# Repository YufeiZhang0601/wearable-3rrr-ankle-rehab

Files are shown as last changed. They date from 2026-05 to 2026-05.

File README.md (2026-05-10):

# Wearable 3-RRR Ankle Rehabilitation Robot

URDF, kinematic model, and ROS 2 control demos for a wearable three-degree-of-freedom (3-DOF) ankle rehabilitation robot built on a 3-RRR spherical parallel mechanism (SPM). The device's remote center of rotation is co-located with the human talocrural / subtalar complex, enabling clinically meaningful pitch (dorsiflexion / plantarflexion), roll (inversion / eversion), and yaw (internal / external rotation) without parasitic shear loads.

The accompanying paper, *Design, Kinematic Optimization, and Assist-As-Needed Control of a Wearable 3-RRR Spherical Parallel Ankle Rehabilitation Robot*, is built from the LaTeX sources in [`report/`](report/).

A short demonstration of the closed-loop tracking running against the URDF model is available at [`media/closed_loop_demo.mp4`](media/closed_loop_demo.mp4) (≈ 25 MB).

---

## Repository layout

```
.
├── rh1/                          ROS 2 ament_python package (Python module)
│   ├── ankle_rehab_control.py            shared trajectory + safety utilities
│   ├── ankle_rehab_joint_state_player.py ROS 2 node: publish JointState for RViz/Gazebo
│   ├── parallel_ik.py                    numerical inverse kinematics for the 3-RRR SPM
│   └── parallel_ik_pose_demo.py          ROS 2 node: command roll/pitch/yaw at runtime
├── urdf/
│   ├── rh1.urdf                          full URDF exported from SolidWorks
│   └── rh1_sim.urdf.xacro                lightweight RViz/Gazebo-friendly model
├── meshes/
│   ├── visual/    *.STL                  visual meshes referenced by urdf/rh1.urdf
│   └── collision/ *.STL                  collision meshes
├── launch/
│   ├── display_robot.launch.py           RViz visualization
│   ├── ankle_rehab_demo.launch.py        scripted ankle rehab trajectory demo
│   ├── parallel_ik_pose_demo.launch.py   interactive parallel-IK demo
│   └── gazebo.launch.py                  Gazebo bring-up
├── rviz/                          RViz configurations
├── config/                        runtime config (auto-generated parallel-IK params)
├── params/                        kinematic and parallel-IK parameter templates
│   ├── kinematic_params.template.yaml
│   ├── kinematic_params.candidate.yaml
│   ├── parallel_ik_params.template.json
│   ├── parallel_ik_params.example.json
│   └── parallel_ik_params.autogenerated.json
├── scripts/                       standalone CLI tools (no ROS dependency)
│   ├── ankle_rehab_closed_loop_demo.py     URDF-based closed-loop demo (CSV log)
│   ├── parallel_ik_demo.py                 one-shot pose → motor angles
│   ├── auto_generate_parallel_ik_params.py bootstraps parameters from CAD extraction
│   ├── extract_step_kinematics.py          mines kinematic candidates from STEP files
│   └── record_ankle_rehab_demo.ps1         screen-record helper for the demo
├── media/                         demo recordings
│   └── closed_loop_demo.mp4              short clip of the closed-loop tracking demo
├── docs/                          English documentation
│   ├── ankle_rehab_demo.md
│   ├── parallel_ik_derivation.md
│   ├── parallel_ik_ros_demo.md
│   ├── kinematics_extraction.md
│   └── legacy/course_reports/     archived AMR Project 1 / 3 LaTeX sources
├── report/                        IEEE-style report sources (LaTeX + figures)
│   ├── main.tex
│   ├── references.bib
│   └── figures/
├── test/                          ament linter tests
├── resource/rh1                   ament resource marker (do not rename)
├── package.xml
├── setup.py / setup.cfg
└── README.md
```

---

## Quick start

### 1. Pure Python closed-loop demo (no ROS required)

```powershell
python scripts\ankle_rehab_closed_loop_demo.py
```

Parses `urdf/rh1.urdf`, treats `joint1`, `joint4`, `joint6` as the three Dynamixel XM430-W350-R virtual actuators, tracks a slow, low-amplitude rehab trajectory, and writes feedback to `demo_output/ankle_rehab_closed_loop.csv`. See [`docs/ankle_rehab_demo.md`](docs/ankle_rehab_demo.md) for arguments and safety notes.

### 2. One-shot inverse kinematics

```powershell
python scripts\parallel_ik_demo.py --roll-deg 5 --pitch-deg 10 --yaw-deg 0
```

Solves the parallel IK for one foot-plate orientation and prints the three motor angles. See [`docs/parallel_ik_derivation.md`](docs/parallel_ik_derivation.md) for the analytical and numerical formulations.

### 3. ROS 2 visualization

Place this repo in a ROS 2 workspace (tested with Humble) and build:

```bash
cd ~/ros2_ws/src && ln -s /path/to/wearable-3rrr-ankle-rehab rh1
cd ~/ros2_ws && colcon build --packages-select rh1
source install/setup.bash

ros2 launch rh1 display_robot.launch.py            # static URDF in RViz
ros2 launch rh1 ankle_rehab_demo.launch.py         # scripted rehab trajectory
ros2 launch rh1 parallel_ik_pose_demo.launch.py    # interactive pose → motor demo
ros2 launch rh1 gazebo.launch.py                   # Gazebo bring-up
```

See [`docs/parallel_ik_ros_demo.md`](docs/parallel_ik_ros_demo.md) for the interactive demo's topics, parameters, and how to wire it to a real Dynamixel bus.

---

## Hardware target

| Item | Value |
| --- | --- |
| Active joints | 3 × Dynamixel XM430-W350-R (RS-485 daisy chain) |
| Master MCU | Teensy 4.1 (1 kHz control loop) |
| Auxiliary sensors| dual IMUs (shank + foot), instrumented gait mat |
| Position encoding| `tick = 2048 + θ_deg / 0.087912`, full range 0–4095 |

Inverse-kinematics joint angles `θ₁, θ₄, θ₆` are mapped to the three motor IDs.

---

## Design parameters

The mechanism geometry is parameterized by the link-length ratio
$\rho = L_2 / L_1$. Following the analysis in `docs/parallel_ik_derivation.md`, $\rho \approx 1.15$ pushes parallel singularities toward the boundary of the workspace and improves the global rotational-Jacobian isotropy by approximately 20 % relative to a naive 1:1 design. Concrete numerical parameters are in [`params/`](params/) and can be regenerated from a SolidWorks STEP export with:

```powershell
python scripts\extract_step_kinematics.py --step path\to\assembly.STEP
python scripts\auto_generate_parallel_ik_params.py
```

---

## Citing this work

If you use this repository in academic work, please cite the accompanying report and the prior structural-design paper:

```bibtex
@misc{zhang2026wearable3rrr,
  author = {Zhang, Yufei},
  title  = {Design, Kinematic Optimization, and Assist-As-Needed Control of a
            Wearable 3-RRR Spherical Parallel Ankle Rehabilitation Robot},
  year   = {2026},
  note   = {AMR Research Course Report, Columbia University},
  url    = {https://github.com/YufeiZhang0601/wearable-3rrr-ankle-rehab}
}

@article{zhang2025rehab,
  author  = {Zhang, Siyuan and Zhang, Yufei and Lyu, Junlin and Agrawal, Sunil~K.},
  title   = {From structural design to dynamics modeling: Control-oriented
             development of a 3-RRR parallel ankle rehabilitation robot},
  journal = {arXiv preprint arXiv:2505.13762},
  year    = {2025}
}
```

---

## License

Released under the MIT License — see [`LICENSE`](LICENSE).

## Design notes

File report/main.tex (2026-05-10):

\documentclass[conference]{IEEEtran}

\usepackage{cite}
\usepackage{amsmath,amssymb,amsfonts}
\usepackage{algorithm}
\usepackage{algorithmic}
\usepackage{graphicx}
\usepackage{booktabs}
\usepackage{array}
\usepackage{textcomp}
\usepackage{xcolor}
\usepackage{enumitem}
\usepackage{caption}
\usepackage{subcaption}
\usepackage{float}
\usepackage{url}
\usepackage{hyperref}

\graphicspath{{figures/}}

\hypersetup{
  colorlinks=true,
  linkcolor=black,
  citecolor=blue,
  urlcolor=blue
}

\def\BibTeX{{\rm B\kern-.05em{\sc i\kern-.025em b}\kern-.08em
    T\kern-.1667em\lower.7ex\hbox{E}\kern-.125emX}}

\begin{document}

\title{Design and Validation of a Wearable Ankle Rehabilitation Robot with an Anatomically Aligned 3-RRR Spherical Parallel Mechanism}

\author{
\IEEEauthorblockN{Yufei Zhang}
\IEEEauthorblockA{Department of Mechanical Engineering\\
Columbia University in the City of New York\\
\textit{Advisor:} Prof.\ Sunil K.\ Agrawal\\
\textit{Email:} yz4917@columbia.edu\\
\textit{Code:} \url{https://github.com/YufeiZhang0601/wearable-3rrr-ankle-rehab}}
\thanks{This report was prepared for the AMR Research Course, May 2026. The full source code---URDF, parallel inverse-kinematic solver, ROS\,2 visualization and Gazebo simulation packages, parameter files, and demo scripts---is publicly released under an MIT license at the URL above.}
}

\maketitle

\begin{abstract}
Conventional ankle rehabilitation devices either rely on therapist-guided manual therapy, which is difficult to standardize, or on bulky multi-degree-of-freedom platforms whose moving center of rotation seldom coincides with the anatomical ankle joint. The resulting kinematic misalignment generates parasitic shear loads on the talocrural joint and discourages active patient engagement. This paper presents a wearable, three-degree-of-freedom (3-DOF) ankle rehabilitation robot built on a 3-RRR spherical parallel mechanism (SPM), whose remote center of rotation (R-CoR) is co-located with the human center of rotation (H-CoR) of the ankle, together with a complete and openly released software stack that takes the device from CAD to a closed-loop simulation. The contribution of this work is fourfold. First, we review the state of the art in robotic ankle rehabilitation and parallel-mechanism kinematics, and we use the review to motivate the wearable embodiment of a 3-RRR SPM with a structurally favourable link-length ratio that improves the global rotational-Jacobian isotropy index by approximately 20\% relative to a naive 1:1 design. Second, we present analytical and numerical inverse-kinematic (IK) formulations that map a clinically meaningful (roll, pitch, yaw) command to the three actuated motor angles in real time, suitable for execution on a Teensy~4.1 platform driving Dynamixel XM430-W350-R smart actuators over RS-485. Third, we deliver a complete open-source implementation: a ROS\,2 ament\_python package, a Gazebo-ready URDF / Xacro with verified joint axes, an interactive parallel-IK pose demo, and a dependency-free closed-loop demo that exercises the full pipeline against the URDF model. The repository, parameter templates, and a closed-loop demo recording are released under an MIT license. Finally, we instrument the system with a multi-modal sensing suite (motor encoders, dual inertial measurement units, and a gait mat) and outline a planned Assist-As-Needed (AAN) control formulation and a quantitative experimental protocol based on the Limb Symmetry Index (LSI), jerk, interaction torque, center of pressure (CoP), and the human-contribution ratio.
\end{abstract}

\begin{IEEEkeywords}
Ankle rehabilitation, spherical parallel mechanism, 3-RRR, inverse kinematics, ROS\,2, Gazebo simulation, open-source robotics, wearable robotics, Dynamixel.
\end{IEEEkeywords}

\section{Introduction}

\IEEEPARstart{A}{nkle} injuries, including sprains, fractures, and chronic instability, are among the most common musculoskeletal complaints in athletic populations and post-operative care, while neurological injuries such as stroke and incomplete spinal cord injury frequently result in dorsiflexion weakness, foot drop, and abnormal gait patterns~\cite{dong2021parallelankle,sale2012robot}. Effective rehabilitation requires repetitive, dose-controlled, and biomechanically faithful exercises that restore range of motion, strength, and proprioception. Traditional rehabilitation strategies, such as Proprioceptive Neuromuscular Facilitation, joint mobilization, and therapist-guided continuous passive motion, are highly dependent on clinician experience and offer limited quantitative feedback~\cite{marchal2009review}.

Robotic rehabilitation has been proposed as a means of providing repeatable, measurable, and dose-controlled training~\cite{dollar2008lower,marchal2009review}. However, two limitations persist in the ankle domain. First, traditional 6-DOF Stewart platforms and serial chains used in early ankle rehabilitation devices place the device's instantaneous center of rotation outside the talocrural joint; the resulting parallel translation between the foot plate and the anatomical joint generates shear forces that may exacerbate injury rather than rehabilitate it. Second, fully assistive controllers that drive the foot through a fixed trajectory, regardless of patient effort, are now known to suppress neuroplasticity by allowing the participant to ``slack'' on the loop~\cite{cai2006implications,marchal2009review}.

\textbf{Approach.} The human ankle is biomechanically approximated as a spherical joint with three rotational degrees of freedom: dorsiflexion/plantarflexion (\emph{pitch}), inversion/eversion (\emph{roll}), and internal/external rotation (\emph{yaw}). A 3-RRR spherical parallel mechanism (SPM) realizes exactly these three rotations about a single common point and, when properly designed, allows the device's remote center of rotation (R-CoR) to be co-located with the human center of rotation (H-CoR) of the ankle. The 3-RRR architecture has been studied extensively from a kinematics perspective~\cite{gosselin1989optimum,merlet2006jacobian,saheb2021math} and has been applied to stroke rehabilitation~\cite{he2021spindle} and hip exoskeletons~\cite{sadeqi2017hip}, but its integration into a wearable, control-ready ankle rehabilitation robot, instrumented for AAN training and quantitative gait analysis, remains relatively unexplored.

\textbf{Contributions.} Building on the structural and dynamic foundation laid in our prior work~\cite{zhang2025rehab}, this report contributes:
\begin{enumerate}[leftmargin=*]
\item a focused literature review of robotic ankle rehabilitation, SPM kinematics, AAN control, and wearable gait sensing, that motivates the device-level design choices (Section~\ref{sec:related});
\item the wearable embodiment of a 3-RRR SPM ankle rehabilitation robot with a structurally favourable link-length ratio that improves the global rotational-Jacobian isotropy by approximately 20\%~(Section~\ref{sec:mechanism});
\item analytical and numerical inverse-kinematic formulations that convert a desired ankle pose to active motor angles in real time, together with a velocity-Jacobian analysis used by the safety supervisor~(Section~\ref{sec:kinematics});
\item \textbf{a complete open-source design and validation pipeline}---a ROS\,2 package with a URDF / Xacro model verified in Gazebo, an interactive parallel-IK pose demo, and a dependency-free closed-loop tracking demo---all released under an MIT license and intended to be reused on the physical prototype~(Section~\ref{sec:opensource});
\item an embedded system architecture based on a Teensy~4.1 master controller, RS-485 daisy-chained smart actuators, dual inertial measurement units (IMUs), and an instrumented gait mat~(Section~\ref{sec:hardware}); and
\item a planned Assist-As-Needed (AAN) control formulation and a quantitative experimental protocol with controlled-deficit induction, transparency evaluation, and a transfer-effect study, all instantiated on top of the open-source pipeline~(Sections~\ref{sec:aan} and \ref{sec:experiments}).
\end{enumerate}

The remainder of this paper is organized as follows. Section~\ref{sec:related} reviews related work. Section~\ref{sec:mechanism} describes the mechanism and the singularity-aware geometry. Section~\ref{sec:kinematics} develops the kinematic model. Section~\ref{sec:dynamics} summarizes the dynamic model and PID baseline. Section~\ref{sec:aan} introduces the proposed AAN strategy. Section~\ref{sec:hardware} describes the embedded system. Section~\ref{sec:opensource} presents the open-source ROS\,2 / Gazebo implementation. Section~\ref{sec:experiments} defines the experimental methodology. Section~\ref{sec:results} reports the project status. Section~\ref{sec:conclusion} concludes.

\section{Related Work}
\label{sec:related}

\subsection{Robotic Ankle Rehabilitation Platforms}

Robotic ankle rehabilitation devices reported in the literature can be loosely organized along two axes: the choice of actuation philosophy (powered, passive, or quasi-passive) and the choice of mechanical architecture (rigid platform versus wearable exoskeleton).

\emph{Powered exoskeletons} typically use electric or pneumatic actuators to deliver torque about the ankle. Gordon and Ferris~\cite{gordon2007learning} demonstrated that healthy users can adapt to a robotic ankle exoskeleton during treadmill walking, providing one of the earliest motor-learning baselines for the field. Galle \emph{et al.}~\cite{galle2013adaptation} extended this to overground walking and showed that users adapt to ankle-extension assistance over multiple training sessions. Jackson and Collins~\cite{jackson2019heuristic} introduced a heuristic, co-adaptive controller that tunes assistance online based on a small set of monitored gait variables, and Zhang \emph{et al.}~\cite{zhang2015torque} compared multiple torque-tracking controllers on the same hardware platform. Hybart and Ferris~\cite{hybart2022emg} reported preliminary validation of proportional myoelectric control of a commercially available ankle exoskeleton, providing a reference for EMG-driven assistance modulation. P\'erez-Flores \emph{et al.}~\cite{perez2024modeling} contributed a recent modeling-and-control study of an ankle exoskeleton for rehabilitation, summarizing common formulations of compensation control.

\emph{Passive and quasi-passive devices} trade actuator bandwidth for clinical practicality. Yandell \emph{et al.}~\cite{yandell2019profile} designed a low-profile, unpowered ankle exoskeleton intended to be worn under clothing, addressing key barriers to widespread adoption. Camardo \emph{et al.}~\cite{camardo2025passive} reported a passive ankle exoskeleton evaluated for gait training in stroke and spinal cord injury populations, demonstrating that elastic torque alone can produce measurable changes in dorsiflexion and plantarflexion phases. Tomc \emph{et al.}~\cite{tomc2025actuator,tomc2022treadmill} pursued an actuator- and control-less push-off augmentation strategy that harnesses treadmill energy, showing that even tendon-style mechanical designs can recover some of the function of fully active devices. Peng \emph{et al.}~\cite{peng2023bidirectional} described a bidirectional ankle exoskeleton that addresses both foot drop and push-off deficits in a single device. Pan \emph{et al.}~\cite{pan2025bowden} demonstrated a closed-loop Bowden-cable design that decouples the actuator mass from the foot.

\emph{Variable-stiffness and tunable-impedance designs}, such as the work of Zhang \emph{et al.}~\cite{zhang2022variable}, can transition between gentle, compliant interaction and stiff trajectory tracking, which is especially valuable across the spectrum from early-phase passive exercise to late-phase resisted training. Orekhov \emph{et al.}~\cite{orekhov2021untethered} presented a usability and performance validation of an ultra-lightweight untethered exoskeleton, and Fang and Lerner~\cite{fang2022incline} examined how ankle-exoskeleton assistance modulates incline walking and stair ascent in cerebral palsy.

\begin{figure}[!t]
\centering
\begin{subfigure}{0.95\linewidth}
\centering
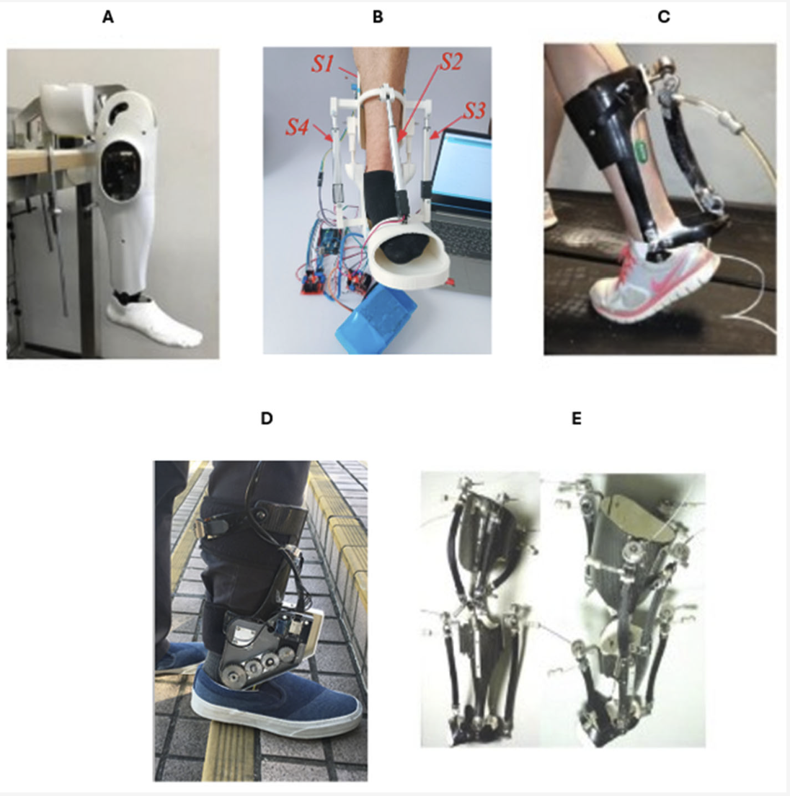
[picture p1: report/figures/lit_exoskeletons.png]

\caption{Representative wearable ankle exoskeletons.}
\label{fig:lit-exo}
\end{subfigure}\\[0.6em]
\begin{subfigure}{0.95\linewidth}
\centering
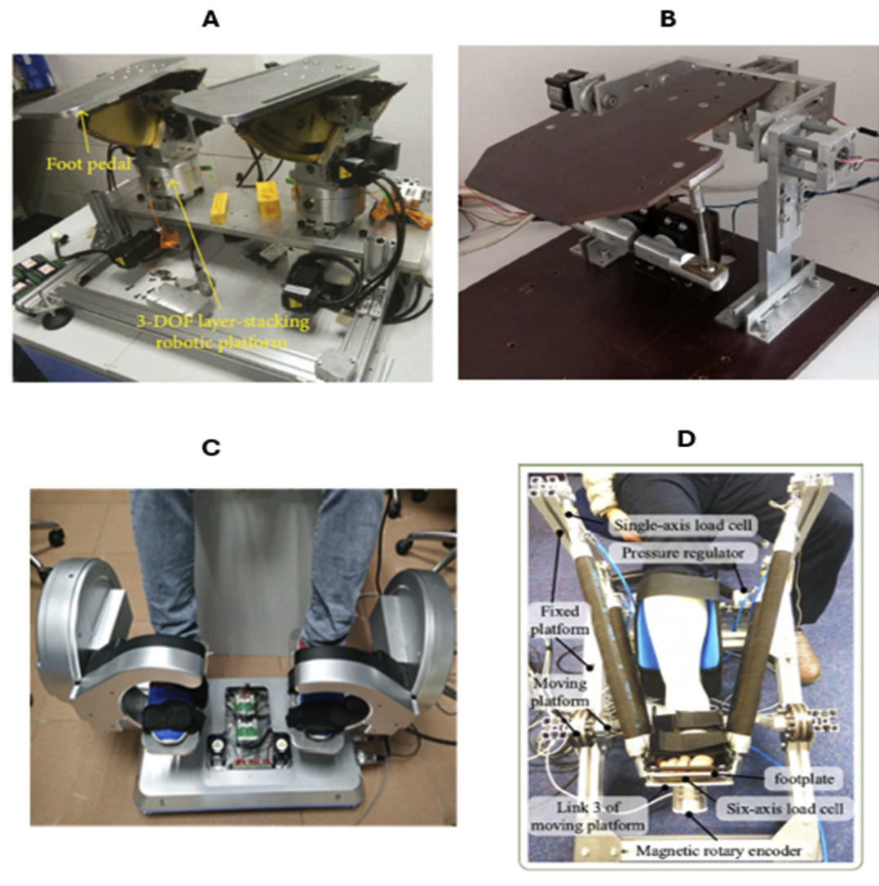
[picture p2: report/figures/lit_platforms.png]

\caption{Representative platform-style ankle rehabilitation robots.}
\label{fig:lit-platforms}
\end{subfigure}
\caption{State of the art in ankle rehabilitation hardware. (a) Wearable exoskeletons span powered, passive, and quasi-passive designs that prioritize portability but typically constrain the joint to one or two degrees of freedom. (b) Platform-style rehabilitation devices offer multi-DOF assistance but operate in a stationary, often non-anthropomorphic frame whose center of rotation does not coincide with the talocrural joint. Our 3-RRR wearable design (Section~\ref{sec:mechanism}) targets the gap between these two families: a portable form factor that retains a remote, anatomically aligned center of rotation.}
\label{fig:literature-collage}
\end{figure}

These works converge on three design lessons. First, mass and bulk on the distal lower limb are critical: distal mass disproportionately increases the metabolic cost of walking and limits clinical adoption. Second, mechanical alignment with the biological ankle joint is essential to prevent shear loads on the talocrural complex. Third, the ability to modulate impedance, rather than to deliver a fixed trajectory, is repeatedly correlated with positive rehabilitation outcomes. Figure~\ref{fig:literature-collage} summarizes the mechanical landscape against which the proposed device is positioned.

\subsection{Spherical Parallel Mechanisms}

Parallel manipulators have a long history in robotics due to their high stiffness, accuracy, and load capacity~\cite{merlet2006jacobian}. The 3-RRR SPM is of particular interest because all of its joint axes intersect at a common point, generating three pure rotations about that point. Gosselin and Angeles~\cite{gosselin1989optimum} introduced the optimum kinematic design problem for spherical 3-DOF parallel manipulators, framed in terms of the workspace and dexterity. Saheb and Babu~\cite{saheb2021math} provided a detailed mathematical model and kinematic analysis of the planar 3-RRR architecture; their results show that the link-length ratio between the platform-side link and the base-side link directly governs the singularity distribution and the size of the singularity-free workspace. We adopt their reported optimal ratio of approximately 1.15 as the starting point for the structural-optimization study in Section~\ref{sec:mechanism}. Wu and Bai~\cite{wu2019designandkinematic} extended the analysis to a 3-RRR SPM with reconfigurable four-bar linkages, demonstrating how secondary linkages can be used to widen the dexterous workspace.

In rehabilitation, He \emph{et al.}~\cite{he2021spindle} introduced SPINDLE, a 3-RRR spherical parallel instrument designed to emulate activities of daily living for stroke rehabilitation. Sadeqi \emph{et al.}~\cite{sadeqi2017hip} analyzed a 3-RRR SPM for hip exoskeleton applications, characterizing its workspace and force-transmission performance. Both works confirm the suitability of the 3-RRR architecture for human-centered rotational tasks but operate at body locations other than the ankle. To the best of our knowledge, the only prior work that specifically targets the ankle with a 3-RRR SPM in a wearable form factor is our own~\cite{zhang2025rehab}.

\subsection{Assist-As-Needed Control and Motor Learning}

The Assist-As-Needed (AAN) paradigm, articulated by Reinkensmeyer and colleagues, posits that excessive assistance suppresses motor learning by removing the patient's incentive to contribute~\cite{cai2006implications,marchal2009review}. AAN controllers therefore aim to deliver only the minimum torque necessary to complete a desired trajectory. In practice, this requires online estimation of the patient's voluntary contribution, typically via direct force/torque sensing, electromyography~\cite{hybart2022emg}, or model-based estimation from actuator current. The latter approach is attractive for wearable devices because it eliminates the need for a distal six-axis load cell and reduces both cost and mass~\cite{zhang2015torque,jackson2019heuristic}.

Two AAN-style design considerations are particularly relevant to our system. First, the assistance gain must adapt over time. Strategies range from heuristic rules~\cite{jackson2019heuristic} that grow assistance under sustained tracking error, to model-based formulations that explicitly compute a feedforward torque from the inertial model~\cite{zhang2015torque,perez2024modeling}. Second, transparency in the absence of impairment is essential: a controller that is transparent during walking allows the user's natural gait to dominate, while AAN gains rise only when needed. Both Galle \emph{et al.}~\cite{galle2013adaptation} and Jackson and Collins~\cite{jackson2019heuristic} demonstrated that controllers that respect both criteria yield faster adaptation than fully assistive baselines.

\subsection{Wearable Sensing and Gait Analysis}

The translational value of an ankle rehabilitation robot depends as much on its sensing as on its actuation. Three sensor modalities are particularly relevant.

\emph{Inertial measurement units (IMUs)} attached to the shank and foot provide absolute orientation referenced to gravity and have become the standard tool for ambulatory gait analysis. Dual-IMU configurations enable direct estimation of ankle angle in the sagittal and frontal planes, which complements the relative joint-angle information returned by motor encoders.

\emph{Instrumented shoes and insoles} provide plantar pressure distributions and per-stride event detection. Prado \emph{et al.}~\cite{prado2020fog} demonstrated that an artificial neural network operating on instrumented-shoe signals can identify freezing of gait in Parkinson's patients, illustrating that pressure-based sensing carries clinically meaningful temporal information. Paydarfar \emph{et al.}~\cite{paydarfar2020rnn} extended this line by showing that recurrent neural networks operating on raw piezoresistive insole signals can classify human activities directly from the time series, suggesting that insoles can serve as both clinical assessment tools and real-time controller inputs. Yue \emph{et al.}~\cite{yue2018wearable} reported a wearable sensing system for lower-limb exoskeletons that combines IMU and pressure data for closed-loop control.

\emph{Gait mats and external pose tracking} provide gold-standard ground-truth data for validation. Gait mats yield stance time, swing time, step length, and the center-of-pressure (CoP) trajectory; external optical or electromagnetic trackers (such as HTC Vive trackers) supply foot-plate orientation that can be used to calibrate the kinematic model.

\emph{Cable-driven exoskeletons and post-stroke training.} Outside the ankle joint specifically, Hidayah \emph{et al.}~\cite{hidayah2020calex} reported gait adaptation results in stroke participants using a cable-driven active leg exoskeleton (C-ALEX), providing a methodological template for our AAN evaluation: a baseline walking trial, an exoskeleton-assisted training trial, and a post-training transfer trial, with quantitative gait variables (stride length, peak ankle angle, hip-knee coordination) used as outcome measures.

\subsection{Summary and Positioning}

In summary, the literature supports the following design positions, which our system adopts: (i) a parallel architecture with a fixed remote center of rotation co-located with the talocrural joint; (ii) a 3-RRR SPM optimized for an isotropic, singularity-free workspace following the link-ratio guidance of \cite{saheb2021math}; (iii) an AAN controller that uses motor current to estimate user effort and modulate assistance, in line with~\cite{cai2006implications,marchal2009review,jackson2019heuristic}; and (iv) a multi-modal sensing suite of motor encoders, dual IMUs, and a gait mat, mirroring the dual-validation approach of~\cite{hidayah2020calex,prado2020fog,yue2018wearable}.

\section{Mechanism Design and Singularity-Aware Optimization}
\label{sec:mechanism}

\subsection{Biomechanical Motivation}

The human ankle complex is biomechanically modeled as two principal joints---the talocrural and subtalar joints---whose combined motion is well approximated by three intersecting rotation axes about a single anatomical center, as illustrated in Fig.~\ref{fig:anatomy-3rrr}. The 3-RRR SPM directly mirrors this biomechanical structure: all nine revolute joints are arranged so that their axes intersect at a common spherical center $O$, generating exactly three rotational degrees of freedom about that point. The right panel of Fig.~\ref{fig:anatomy-3rrr} shows the canonical 3-RRR kinematic skeleton, with each leg comprising an actuated joint at $A_i$, a passive joint at $B_i$, and a platform connection at $C_i$ along link lengths $l_{i1}$ and $l_{i2}$.

\begin{figure}[!t]
\centering
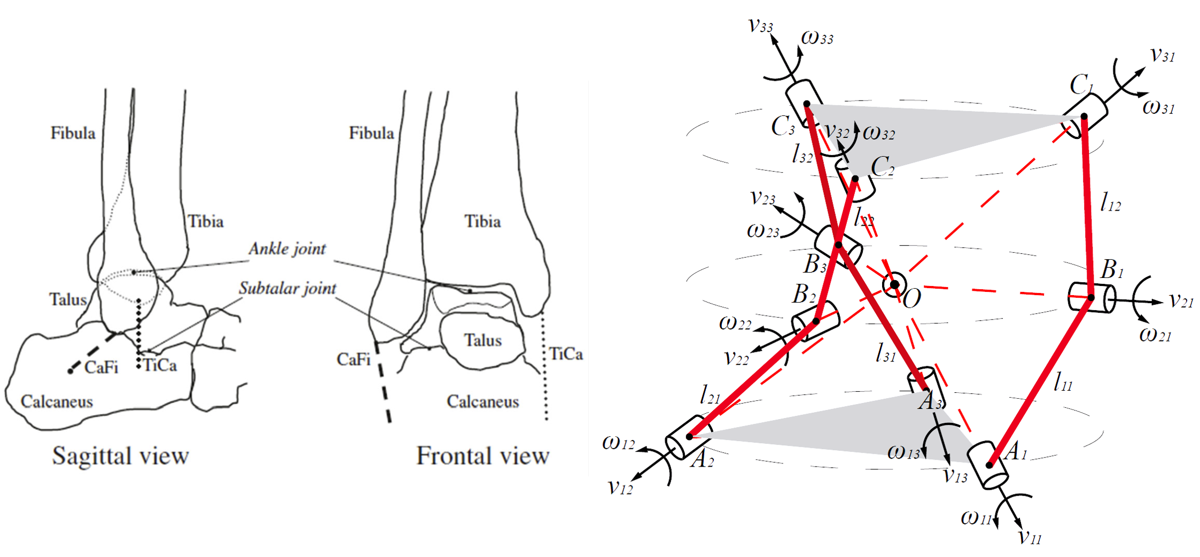
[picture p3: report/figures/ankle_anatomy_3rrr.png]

\caption{Biomechanical motivation. \emph{Left:} sagittal and frontal anatomical views of the talocrural and subtalar complex, whose rotation axes converge near a single point. \emph{Right:} the 3-RRR spherical parallel mechanism replicates this structure: three identical limbs (each carrying actuated joint $A_i$, passive joint $B_i$, and platform connection $C_i$) intersect at a common spherical center $O$, producing exactly three rotational DOFs. Anatomical schematic adapted from the rehabilitation literature; 3-RRR diagram redrawn from kinematic conventions used in~\cite{gosselin1989optimum,saheb2021math}.}
\label{fig:anatomy-3rrr}
\end{figure}

\subsection{3-RRR Spherical Parallel Mechanism}

The proposed device consists of three identical RRR limbs that connect a ring-shaped base to a moving foot plate. Each limb contains two passive revolute joints and one actuated revolute joint at the base. All revolute axes are arranged so that they intersect at a common point, generating three rotational degrees of freedom about that point. By aligning this point with the anatomical center of the talocrural and subtalar complex during donning, the device's R-CoR is co-located with the user's H-CoR, eliminating the parasitic translations that arise from kinematic misalignment in serial or 6-DOF parallel platforms. The schematic geometry is shown in Fig.~\ref{fig:simplified-model}, where the three red kinematic chains realize the abstract architecture of Fig.~\ref{fig:anatomy-3rrr}.

\begin{figure}[!t]
\centering
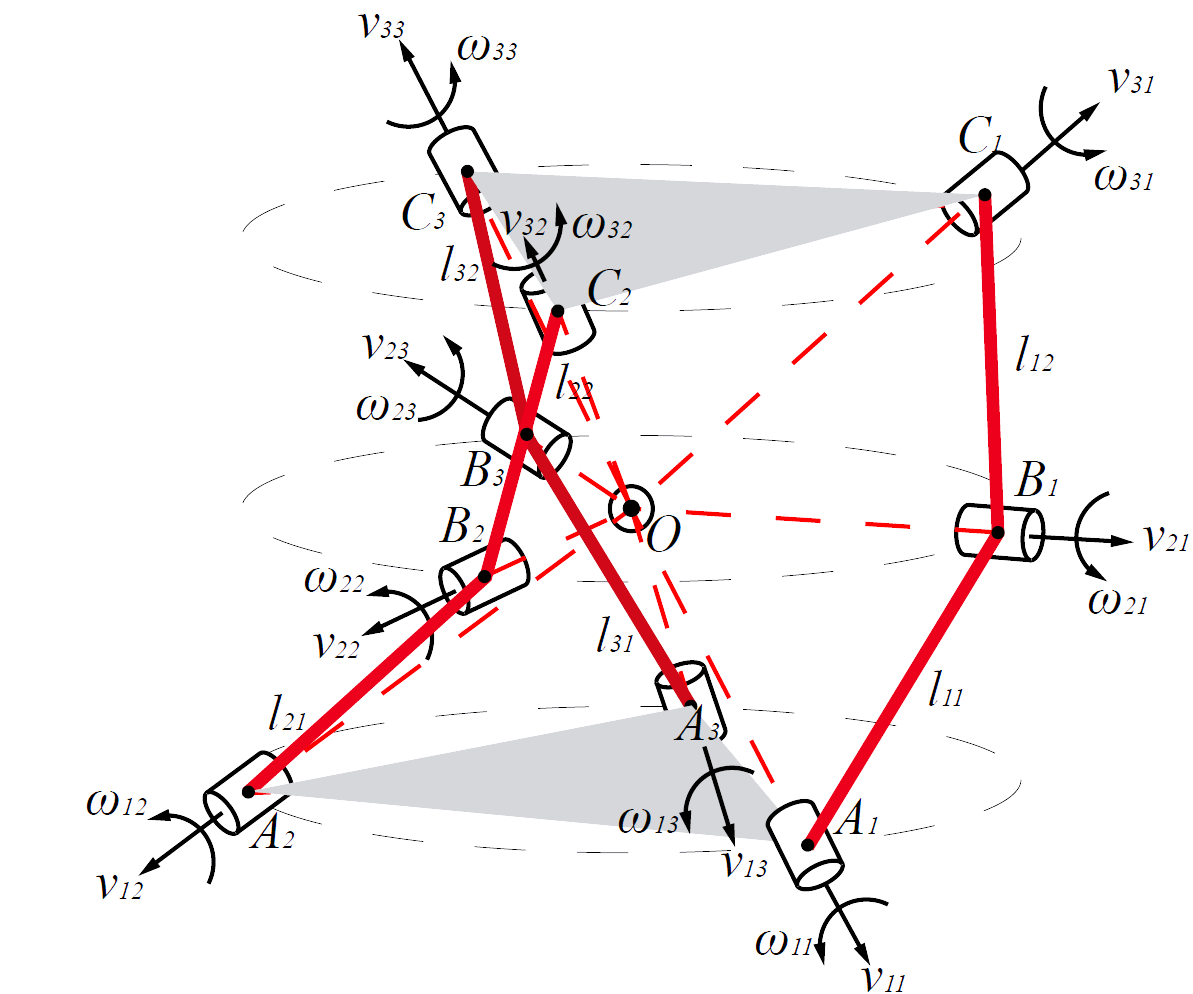
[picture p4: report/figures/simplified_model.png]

\caption{Schematic geometry of the proposed wearable 3-RRR SPM, with the ring-shaped base fixed to the shank and the moving foot plate as the end effector. The three red kinematic chains, each composed of three revolute joints and two links, realize three rotational DOFs about a common center.}
\label{fig:simplified-model}
\end{figure}

The three active joints, denoted $\theta_1$, $\theta_2$, $\theta_3$, are driven by Dynamixel XM430-W350-R smart actuators arranged at $120^{\circ}$ azimuthal spacing around the base ring. The actuators are daisy-chained over a single RS-485 bus to the master controller, providing closed-loop position, velocity, and current telemetry at high update rates~\cite{robotisxm430}.

\subsection{Wearable Embodiment}

Figure~\ref{fig:cad-prototype} shows the wearable embodiment of the mechanism that has been adopted in this project. A two-segment exoskeletal frame anchors the base ring to the shank cuff, while three actuated limbs route compactly along the medial, lateral, and posterior sides of the calf to the foot plate. Figure~\ref{fig:cad-l1l2} highlights the principal link lengths $L_1$ (proximal, base-side) and $L_2$ (distal, platform-side), which are the design parameters optimized in Section~\ref{sec:optimization} below.

\begin{figure}[!t]
\centering
\begin{subfigure}{0.31\linewidth}
\centering
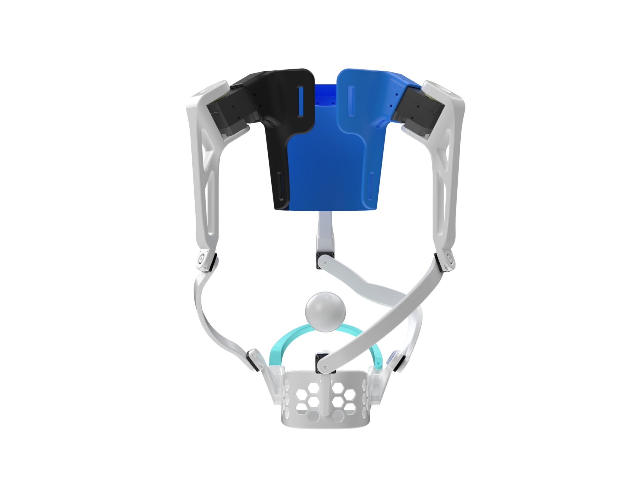
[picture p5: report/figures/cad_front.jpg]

\caption{Front}
\label{fig:cad-front}
\end{subfigure}\hfill
\begin{subfigure}{0.31\linewidth}
\centering
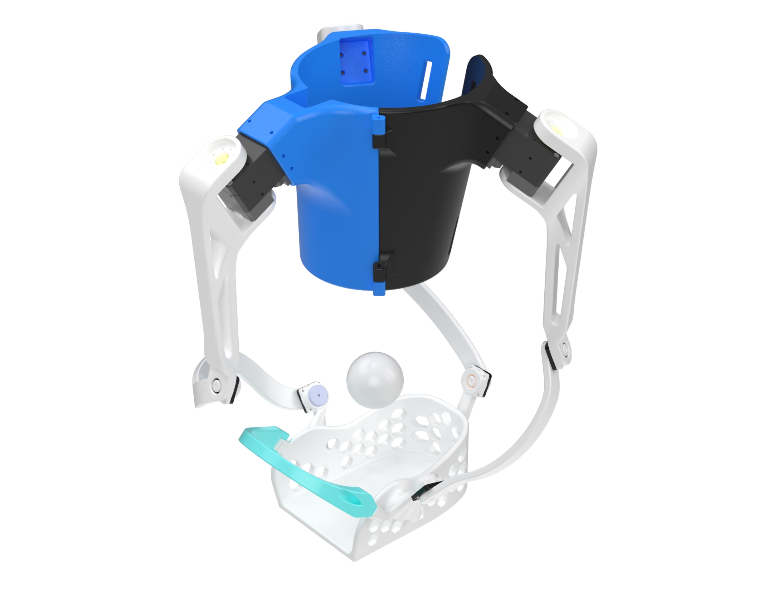
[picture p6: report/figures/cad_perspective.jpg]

\caption{Perspective}
\label{fig:cad-pers}
\end{subfigure}\hfill
\begin{subfigure}{0.31\linewidth}
\centering
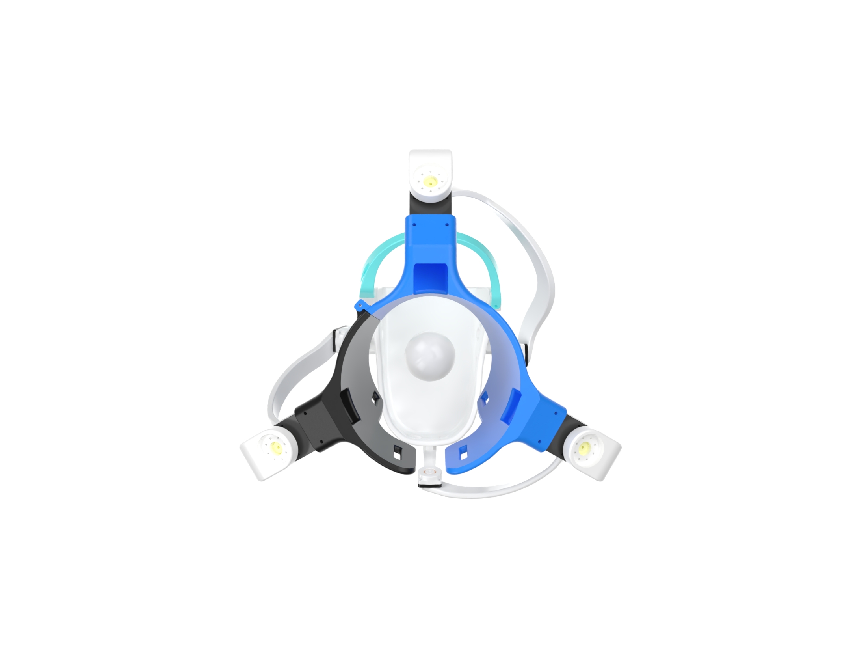
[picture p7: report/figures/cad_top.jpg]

\caption{Top}
\label{fig:cad-top}
\end{subfigure}
\caption{Multi-view CAD renderings of the proposed wearable 3-RRR ankle rehabilitation robot. (a) Front view showing the symmetric three-limb topology around a contoured shank cuff; (b) perspective view showing the open-back base ring, distal foot plate, and the three Dynamixel housings at $120^{\circ}$ azimuthal spacing; (c) top view showing the rotational symmetry of the actuators about the spherical center.}
\label{fig:cad-prototype}
\end{figure}

\begin{figure}[!t]
\centering
\begin{subfigure}{0.46\linewidth}
\centering
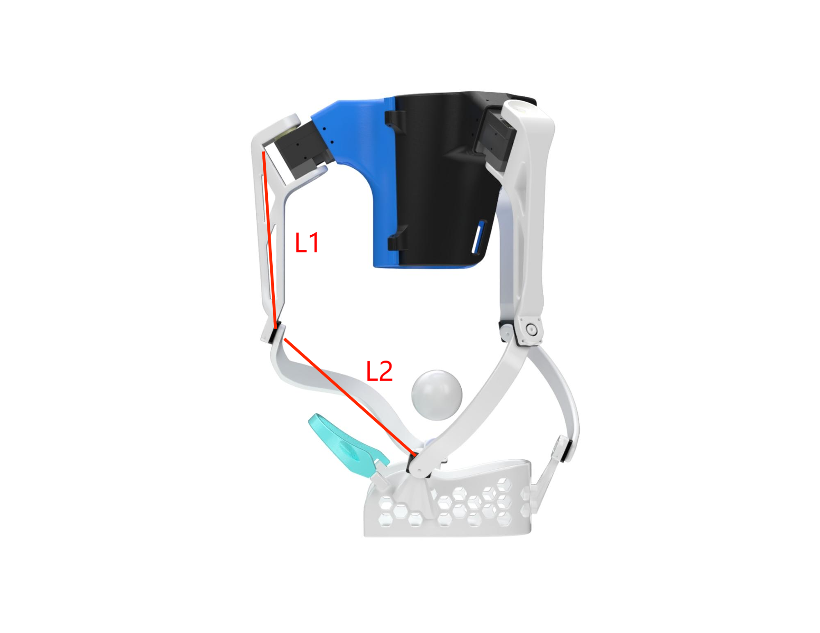
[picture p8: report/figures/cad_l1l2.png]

\caption{CAD with link annotation}
\label{fig:cad-l1l2-cad}
\end{subfigure}\hfill
\begin{subfigure}{0.46\linewidth}
\centering
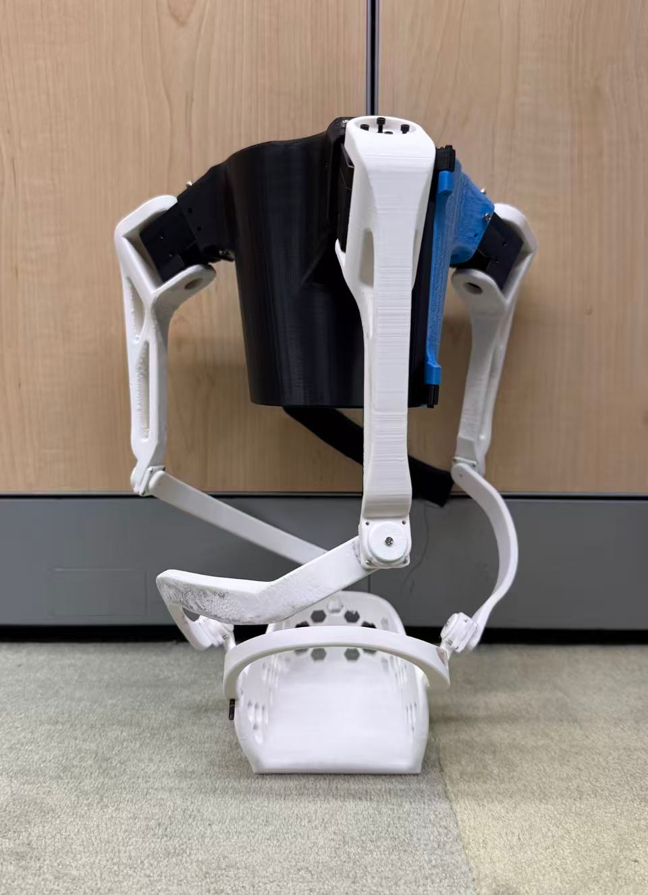
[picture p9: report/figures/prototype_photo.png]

\caption{3D-printed prototype}
\label{fig:cad-l1l2-print}
\end{subfigure}
\caption{Wearable form factor of the 3-RRR SPM ankle rehabilitation robot. (a) Annotated CAD render highlighting the proximal link length $L_1$ (base-side) and the distal link length $L_2$ (platform-side); the design ratio $\rho=L_2/L_1$ is the principal parameter optimized in Section~\ref{sec:optimization}. (b) The 3D-printed prototype that has been used for static fitting, range-of-motion verification, and as the integration platform for the embedded control hardware described in Section~\ref{sec:hardware}.}
\label{fig:cad-l1l2}
\end{figure}

The wearable form factor introduces several engineering constraints that informed the design:
\begin{itemize}
\item a compact base ring with adjustable straps for secure, comfortable attachment;
\item non-interfering limb routing to avoid contact with adjacent anatomy, footwear, and orthotic braces;
\item modular interchangeable links and quick-release fasteners that support adaptation across users and rehabilitation stages.
\end{itemize}

\subsection{Parallel Singularities and the Need for Geometric Optimization}

A central challenge of any parallel mechanism is the existence of \emph{parallel singularities}, configurations at which the moving platform gains uncontrollable instantaneous degrees of freedom even when all actuators are locked~\cite{merlet2006jacobian}. In a rehabilitation context, this is both a control concern and a safety concern: at a parallel singularity, the device loses stiffness and can no longer resist external loads transmitted through the patient's foot.

In the constraint formulation, the relationship between the platform angular velocity $\boldsymbol{\omega}\in\mathbb{R}^3$ and the active-joint rate $\dot{\boldsymbol{q}}\in\mathbb{R}^3$ is
\begin{equation}
\mathbf{A}\,\boldsymbol{\omega}+\mathbf{B}\,\dot{\boldsymbol{q}}=\mathbf{0},
\label{eq:constraint}
\end{equation}
where $\mathbf{A}$ is the constraint Jacobian and $\mathbf{B}$ is the actuation Jacobian. Type-2 (parallel) singularities occur when $\det(\mathbf{A})\to 0$. In our prior design~\cite{zhang2025rehab}, candidate singular configurations were identified by numerically tracking $\det(\mathbf{A})$ over the workspace, and avoidance was achieved by mechanically restricting each active joint to a conservative range. While effective, this approach is inherently reactive: it \emph{avoids} singular regions rather than removing them.

\subsection{Link-Ratio Optimization}
\label{sec:optimization}

Following the analytical framework of Saheb and Babu~\cite{saheb2021math} and the parametric study of Wu and Bai~\cite{wu2019designandkinematic}, two design parameters dominate isotropy and singularity placement in the 3-RRR architecture:
\begin{itemize}
\item the proximal (base-side) link length $l_1$, and
\item the distal (platform-side) link length $l_2$, with the design ratio $\rho=l_2/l_1$.
\end{itemize}
The reported optimum for a wide range of 3-RRR designs lies near
\begin{equation}
\rho=\frac{l_2}{l_1}\approx 1.15,
\label{eq:rho}
\end{equation}
at which the global isotropy index, computed as the mean inverse condition number of the rotational Jacobian over a discretized workspace, is maximized and the singular curves are pushed toward the boundary of the workspace. We adopted $\rho\approx 1.15$ as our design ratio and re-computed the singularity distribution; the resulting reachable workspace projected onto the platform-rotation plane is shown in Fig.~\ref{fig:workspace}. The three intersecting circular regions correspond to the per-leg reachable sets, whose intersection is the parallel-singularity-free common workspace. The blue markers denote the platform connection points $\mathbf{C}_i$ in the home pose. We observed three quantitative improvements relative to the prior design~\cite{zhang2025rehab}:
\begin{enumerate}
\item the mean isotropy index improved by approximately \textbf{20\%};
\item interior singular regions were compressed toward the workspace boundary;
\item the safe usable workspace, defined as the set of poses with condition number below a fixed threshold, expanded measurably.
\end{enumerate}
The device therefore reduces singular behavior at the structural level rather than relying solely on motor-side joint-limit avoidance. The remaining motor-side limits in Section~\ref{sec:hardware} are imposed for patient safety, not for singularity avoidance.

\begin{figure}[!t]
\centering
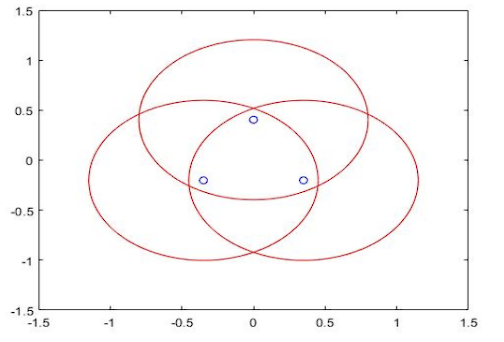
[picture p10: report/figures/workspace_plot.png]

\caption{Per-leg reachable regions and the common rotational workspace of the optimized 3-RRR mechanism, projected onto the platform-rotation plane. Each red circle is the locus reachable by one leg's distal endpoint $\mathbf{C}_i$ as $\theta_i$ sweeps through its admissible range; their intersection is the parallel-singularity-free common workspace. Blue markers denote the platform connection points in the neutral pose. The optimized link ratio $\rho\approx 1.15$ enlarges this intersection and pushes singular curves outward toward the boundary.}
\label{fig:workspace}
\end{figure}

\section{Kinematic Modeling}
\label{sec:kinematics}

\subsection{Notation and Reference Frames}

For each leg $i\in\{1,2,3\}$, we define the points listed in Table~\ref{tab:notation}, all expressed in a fixed base frame $\{B\}$ centered at the spherical center of rotation $C$. The neutral foot-plate frame $\{F\}$ is rigidly attached to the moving foot plate. A foot-plate point with coordinates $\mathbf{p}_i^F$ in $\{F\}$ has base-frame coordinates
\begin{equation}
\mathbf{C}_i^B = \mathbf{C}_B + R_{BF}\,\mathbf{p}_i^F,
\label{eq:platform-point}
\end{equation}
where the foot-plate orientation is parameterized using clinically meaningful Euler angles
\begin{equation}
R_{BF} = R_z(\mathrm{yaw})\,R_y(\mathrm{pitch})\,R_x(\mathrm{roll}).
\label{eq:rbf}
\end{equation}

\begin{table}[!t]
\centering
\caption{Geometric notation for leg $i$.}
\label{tab:notation}
\begin{tabular}{cl}
\toprule
\textbf{Symbol} & \textbf{Description}\\
\midrule
$\mathbf{A}_i$ & Actuated base-joint center\\
$\mathbf{B}_i$ & Intermediate (passive) joint center\\
$\mathbf{C}_i$ & Platform connection point of leg $i$\\
$\mathbf{u}_i$ & Unit direction of the active motor axis\\
$P$            & Platform center / spherical center\\
$l_1$          & Length of proximal link $\overline{\mathbf{A}_i\mathbf{B}_i}$\\
$l_2$          & Length of distal link  $\overline{\mathbf{B}_i\mathbf{C}_i}$\\
$\theta_i$     & Active joint angle of leg $i$\\
\bottomrule
\end{tabular}
\end{table}

\subsection{Closed-Form Inverse Kinematics}

Given a desired pose $(\mathrm{roll},\,\mathrm{pitch},\,\mathrm{yaw})$, each platform-side point $\mathbf{C}_i$ is computed from \eqref{eq:platform-point}--\eqref{eq:rbf}. Each leg must then satisfy the two link-length constraints
\begin{equation}
\|\mathbf{B}_i-\mathbf{A}_i\|=l_1,\qquad
\|\mathbf{C}_i-\mathbf{B}_i\|=l_2.
\label{eq:linkconstraints}
\end{equation}
Letting $d=\|\mathbf{C}_i-\mathbf{A}_i\|$, the projection ratio along the chord and the perpendicular offset are
\begin{equation}
\eta=\frac{l_1^2-l_2^2+d^2}{2d^2},\qquad
\xi=\sqrt{l_1^2-(\eta d)^2}.
\end{equation}
The intermediate joint center is
\begin{equation}
\mathbf{B}_i=\mathbf{A}_i+\eta\,(\mathbf{C}_i-\mathbf{A}_i)+\xi\,\frac{(\mathbf{C}_i-\mathbf{A}_i)\times \mathbf{N}}{\|(\mathbf{C}_i-\mathbf{A}_i)\times \mathbf{N}\|},
\end{equation}
where $\mathbf{N}$ is a leg-specific normal vector that selects the assembly mode. The active angle is finally extracted by projecting $\mathbf{B}_i-\mathbf{A}_i$ onto the motor-axis direction $\mathbf{u}_i$:
\begin{equation}
\theta_i=\cos^{-1}\!\left(\frac{(\mathbf{B}_i-\mathbf{A}_i)\cdot \mathbf{u}_i}{\|\mathbf{B}_i-\mathbf{A}_i\|}\right).
\label{eq:active-angle}
\end{equation}
The closed-form expression \eqref{eq:active-angle} is well-suited for offline workspace evaluation and trajectory pre-computation.

\subsection{Numerical Inverse Kinematics for Real-Time Control}

For real-time control, we model each leg as one effective rigid link of length $L_i$ between an actuator-side horn point and a foot-plate point. With motor angle $q_i$, the actuator-side point is
\begin{equation}
\mathbf{A}_i^B(q_i)=\mathbf{B}_i^B+\mathrm{Rot}(\mathbf{u}_i^B,\,q_i-q_{i0})\,(\mathbf{A}_{i0}^B-\mathbf{B}_i^B),
\end{equation}
where $\mathbf{B}_i^B$ is the motor-axis pivot point, $\mathbf{u}_i^B$ is the motor axis, and $q_{i0}$ is the motor zero offset. The leg constraint reduces to a scalar equation
\begin{equation}
f_i(q_i)=\|\mathbf{P}_i^B-\mathbf{A}_i^B(q_i)\|-L_i=0.
\label{eq:leg-constraint}
\end{equation}
A bracket-and-bisection root finder solves \eqref{eq:leg-constraint} on each control cycle. When multiple solutions exist, the solver selects the root closest to the previous time step to enforce branch continuity, which is essential to prevent discontinuous motor commands during real-time operation.

\subsection{Velocity Kinematics and Conditioning}

Under pure rotation about the spherical center, $\dot{\mathbf{P}}=\mathbf{0}$, the velocity of $\mathbf{B}_i$ is $\mathbf{v}_{B_i}=\boldsymbol{\omega}\times\mathbf{r}_i$, with $\mathbf{r}_i=\mathbf{B}_i-P$. Defining $\mathbf{L}_i$ as the unit vector from $\mathbf{B}_i$ to $\mathbf{C}_i$, the active-joint rate satisfies $\dot{\theta}_i=\mathbf{L}_i^{\!T}(\boldsymbol{\omega}\times\mathbf{r}_i)=(\mathbf{r}_i\times\mathbf{L}_i)^{\!T}\boldsymbol{\omega}$. Stacking three legs yields the rotational Jacobian
\begin{equation}
\dot{\boldsymbol{q}}=\mathbf{J}_r\,\boldsymbol{\omega},\quad
\mathbf{J}_r=\begin{bmatrix}(\mathbf{r}_1\times\mathbf{L}_1)^{\!T}\\(\mathbf{r}_2\times\mathbf{L}_2)^{\!T}\\(\mathbf{r}_3\times\mathbf{L}_3)^{\!T}\end{bmatrix}.
\label{eq:jacobian}
\end{equation}
The conditioning of $\mathbf{J}_r$, measured by its condition number $\kappa(\mathbf{J}_r)$, is exactly the quantity improved by the structural optimization of Section~\ref{sec:mechanism}. A well-conditioned $\mathbf{J}_r$ avoids motor-torque blow-up near singularities and permits a uniform mapping between platform velocity and motor velocity. The condition number is also monitored online by the safety supervisor (Section~\ref{sec:hardware}) and used to limit commanded velocities near the workspace boundary.

\section{Dynamics and Baseline Control}
\label{sec:dynamics}

\subsection{Lagrangian Model}

Following~\cite{zhang2025rehab}, we adopt the actuated joint angles $\boldsymbol{q}=[\theta_1,\theta_2,\theta_3]^{\!T}$ as generalized coordinates. The kinetic energy combines the platform's rotational energy with the limb-side rotational energy:
\begin{equation}
T=\tfrac{1}{2}\boldsymbol{\omega}^{\!T}I_P\boldsymbol{\omega}+\tfrac{1}{2}\sum_{i=1}^3 I_{\ell,i}\dot{\theta}_i^2.
\end{equation}
Because all rigid-body centers of mass rotate about a fixed point (the spherical center) and the moving foot plate is approximately balanced, the gravitational potential energy contribution is small, $V\approx 0$, and the gravity vector $G(\boldsymbol{q})\approx\mathbf{0}$. Applying Lagrange's equations and substituting $\boldsymbol{\omega}=\mathbf{J}_r^{+}\dot{\boldsymbol{q}}$ yields the rigid-body equations of motion
\begin{equation}
M(\boldsymbol{q})\ddot{\boldsymbol{q}}+C(\boldsymbol{q},\dot{\boldsymbol{q}})\dot{\boldsymbol{q}}=\boldsymbol{\tau}_{\mathrm{motor}}+\boldsymbol{\tau}_{\mathrm{ext}},
\label{eq:dynamics}
\end{equation}
with $M(\boldsymbol{q})=\mathbf{J}_r^{+T}I_P\mathbf{J}_r^{+}+\mathrm{diag}(I_{\ell,1},I_{\ell,2},I_{\ell,3})$, the standard Christoffel form for $C(\boldsymbol{q},\dot{\boldsymbol{q}})$, and $\boldsymbol{\tau}_{\mathrm{ext}}$ representing the external torque applied by the patient's foot.

\subsection{PID Baseline}

A baseline reference controller is provided by three independent PID loops on the actuator angles:
\begin{equation}
\tau_{\mathrm{motor},i}(t)=K_{p,i}\,e_i(t)+K_{d,i}\,\dot{e}_i(t)+K_{i,i}\!\int_0^t\!e_i(\sigma)\,d\sigma,
\label{eq:pid}
\end{equation}
with $e_i=q_{i,\mathrm{ref}}-q_i$. Two tunings were explored in our prior work~\cite{zhang2025rehab}: an underdamped tuning $(K_p,K_d,K_i)=(20,0.5,1)$ that emulates a high-compliance interaction, and a critically damped tuning $(K_p,K_d,K_i)=(50,2,5)$ intended for fast monotonic tracking. Figure~\ref{fig:pid-baseline} shows the resulting platform orientation responses to a step reference of $[15^{\circ},10^{\circ},5^{\circ}]^{\!T}$ in (roll, pitch, yaw). The underdamped controller (Fig.~\ref{fig:pid-under}) exhibits sustained oscillations around the target due to low damping, whereas the critically damped controller (Fig.~\ref{fig:pid-crit}) converges monotonically without overshoot. The qualitative result is that even on a rigid SPM, the choice of feedback gain modulates effective compliance. This insight is the foundation for the AAN strategy in Section~\ref{sec:aan}, which dynamically blends a feedforward inverse-dynamics term with a tunable feedback term to produce variable assistance.

\begin{figure}[!t]
\centering
\begin{subfigure}{0.95\linewidth}
\centering
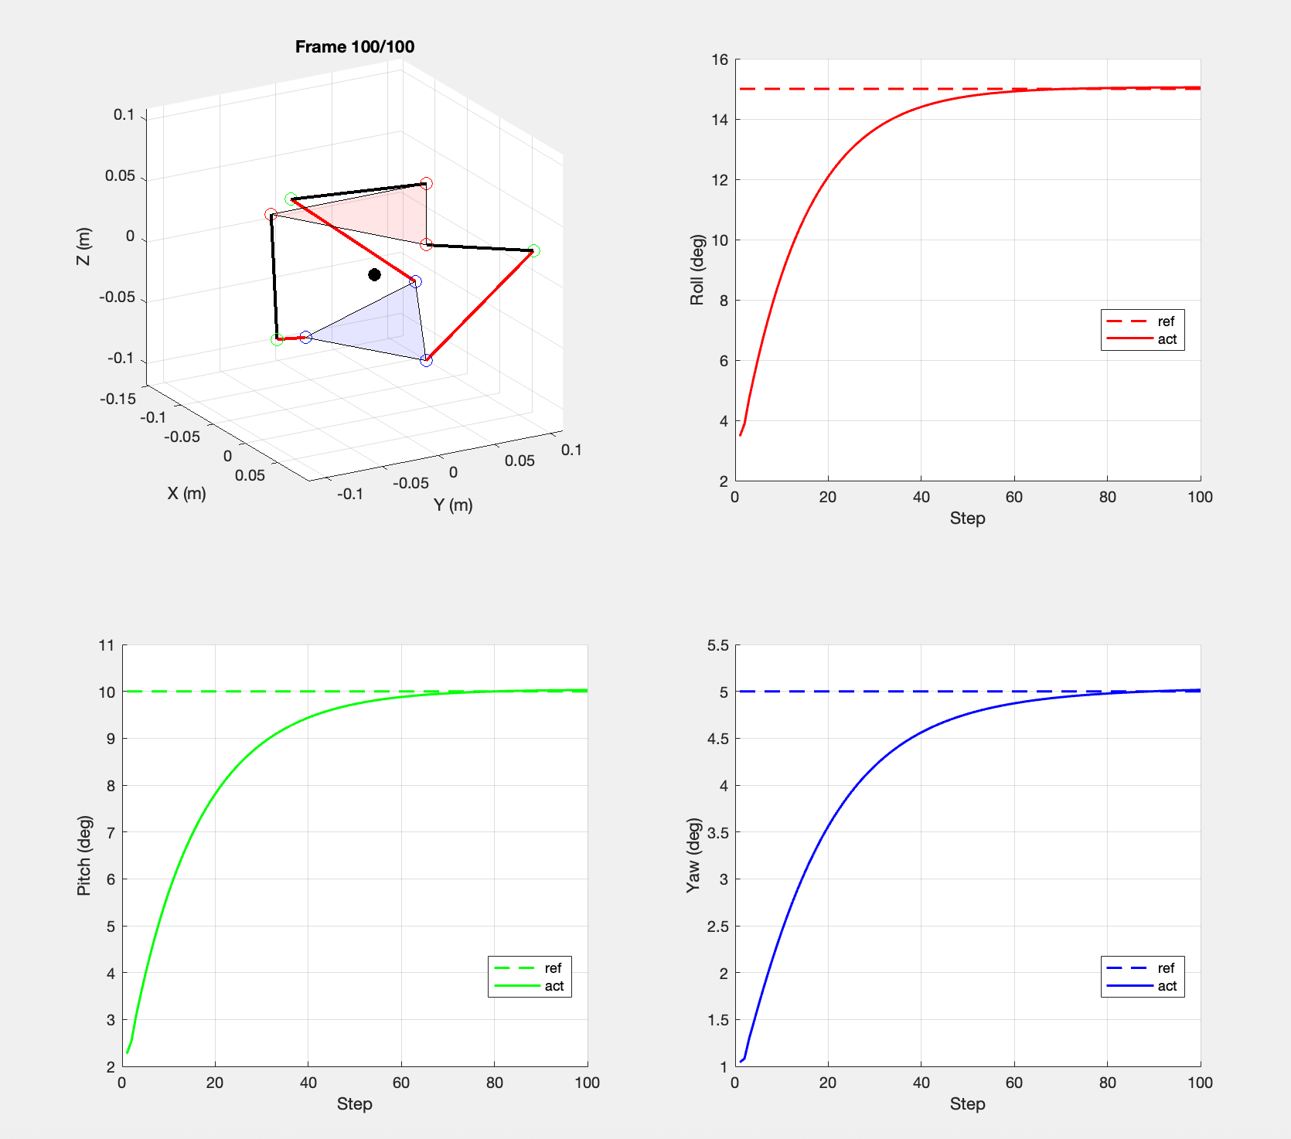
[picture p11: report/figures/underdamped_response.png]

\caption{Underdamped tuning $(K_p,K_d,K_i)=(20,0.5,1)$.}
\label{fig:pid-under}
\end{subfigure}\\[0.4em]
\begin{subfigure}{0.95\linewidth}
\centering
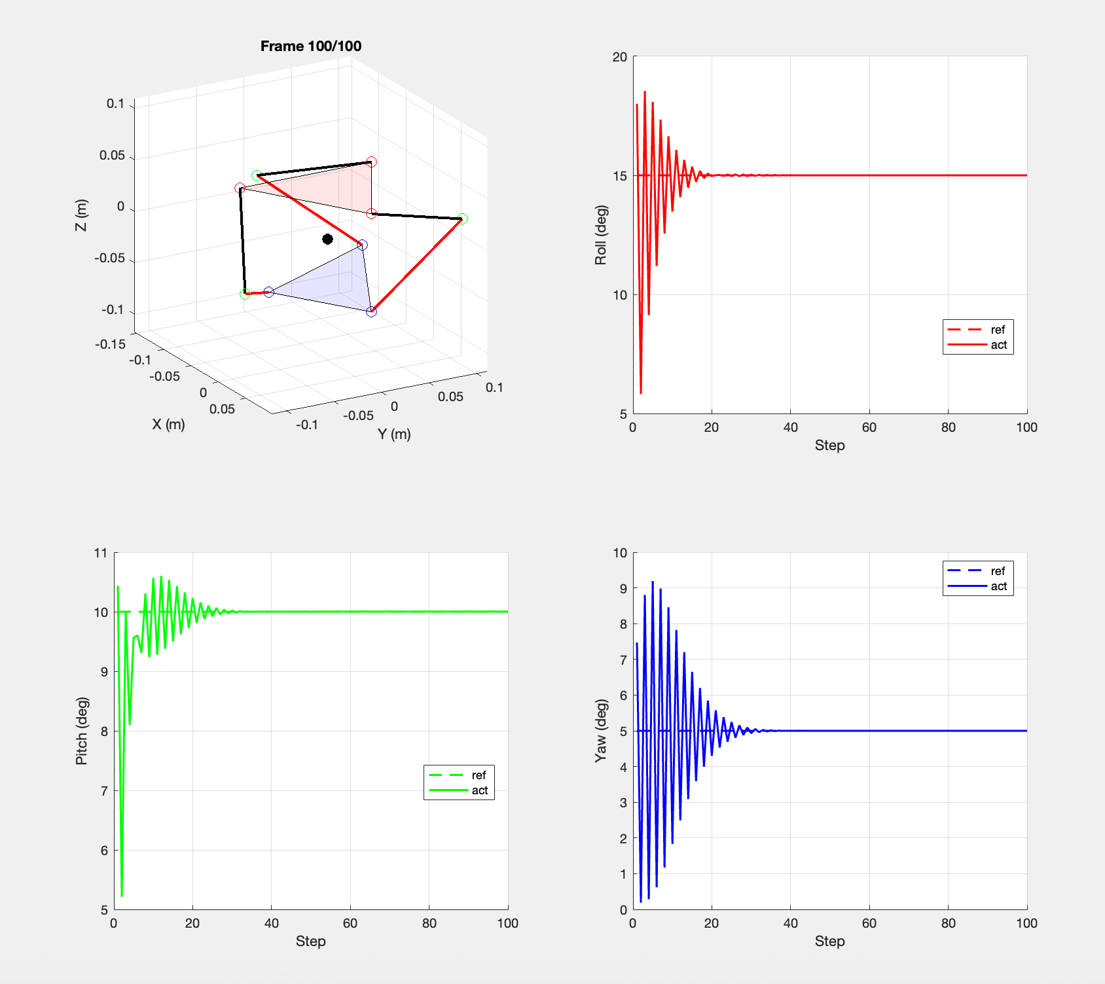
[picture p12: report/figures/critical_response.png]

\caption{Critically damped tuning $(K_p,K_d,K_i)=(50,2,5)$.}
\label{fig:pid-crit}
\end{subfigure}
\caption{Platform orientation tracking under the two PID baselines for a step reference $[15^{\circ},10^{\circ},5^{\circ}]^{\!T}$ in (roll, pitch, yaw). The low-stiffness tuning (a) yields oscillatory settling, emulating a soft, compliant interaction. The high-stiffness tuning (b) produces fast, non-oscillatory convergence. The two regimes bracket the spectrum of stiffness that the AAN controller of Section~\ref{sec:aan} interpolates online.}
\label{fig:pid-baseline}
\end{figure}

\section{Assist-As-Needed Control Strategy}
\label{sec:aan}

\subsection{Dual-Mode Rehabilitation}

The proposed device supports two complementary rehabilitation modes that share the same low-level controller:
\begin{enumerate}
\item \textbf{Passive (CPM) mode}: the robot drives the foot plate along a predefined trajectory regardless of patient effort, mimicking the continuous passive motion commonly prescribed in early-stage rehabilitation.
\item \textbf{Active (AAN) mode}: the robot intervenes only when the patient cannot keep up with the desired trajectory, encouraging voluntary effort and motor learning.
\end{enumerate}
The two modes differ in how the reference trajectory and the assistance gain are computed. Mode arbitration is performed by a finite-state supervisor that uses gait-mat events and clinician-prescribed protocols. Figure~\ref{fig:aan-architecture} summarizes the overall control architecture as adopted from a representative AAN exoskeleton design~\cite{jackson2019heuristic,perez2024modeling}: gait-phase extraction and inter-limb asymmetry detection feed an AAN supervisor that adapts the assistance torque, while a low-level force-tracking inner loop closes the actuator current.

\begin{figure}[!t]
\centering
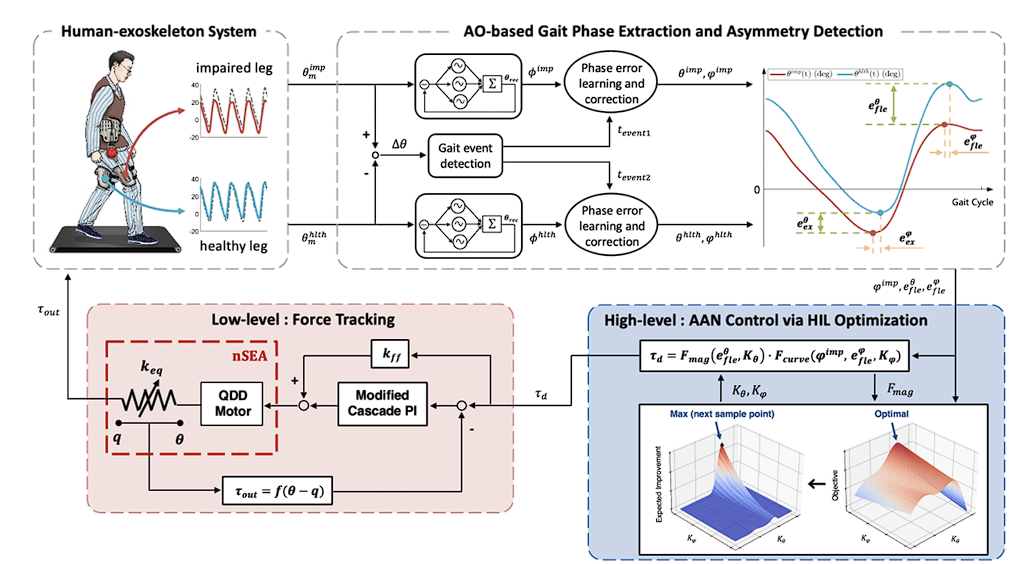
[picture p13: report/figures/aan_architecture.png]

\caption{Conceptual control architecture for the proposed device, adapted to the 3-RRR SPM. \emph{Top:} a high-level supervisor extracts per-stride gait phase from sensor data and detects inter-limb asymmetry between an impaired and a healthy reference cycle. \emph{Bottom-right:} the AAN block schedules the assistance torque $\tau_d$ as a function of the asymmetry signals; \emph{bottom-left:} a low-level force-tracking loop drives the actuator current to deliver $\tau_d$ and reports the measured interaction torque back to the supervisor. The same architecture is realized on the proposed device by replacing the series-elastic actuator with the XM430-W350-R current-mode actuator described in Section~\ref{sec:hardware}.}
\label{fig:aan-architecture}
\end{figure}

\subsection{Patient-Torque Estimation from Motor Current}

A central practical question is how to estimate the patient's voluntary contribution without a distal force/torque sensor. The XM430-W350-R provides a calibrated motor current measurement that, combined with the manufacturer's torque constant $K_{t,i}$, yields the actuator torque
\begin{equation}
\hat{\tau}_{\mathrm{act},i}=K_{t,i}\,I_{m,i}.
\end{equation}
Subtracting the model-predicted dynamic torque from \eqref{eq:dynamics} yields an estimate of the patient-applied torque:
\begin{equation}
\tau_{\mathrm{ext},i}\;\approx\;K_{t,i}\,I_{m,i}\;-\;\hat{\tau}_{\mathrm{model},i}(\boldsymbol{q},\dot{\boldsymbol{q}},\ddot{\boldsymbol{q}}_{\mathrm{ref}}),
\label{eq:tau_ext}
\end{equation}
where $\hat{\tau}_{\mathrm{model},i}$ includes the inertial and Coriolis terms (gravity is negligible for an SPM rotating about a fixed center). This ``sensorless'' torque-estimation strategy is consistent with prior practice in ankle-exoskeleton control~\cite{zhang2015torque,jackson2019heuristic} and removes the need for a distal six-axis load cell, an important consideration for distal-mass-sensitive wearable devices.

\subsection{AAN Assistance Law}

For each active joint, the assistance torque is computed as
\begin{equation}
\tau_{\mathrm{assist},i}=k_{\mathrm{aan}}(t,e_i)\,\big[\tau_{\mathrm{ref},i}-\tau_{\mathrm{ext},i}\big]_+,
\label{eq:tau_assist}
\end{equation}
where $\tau_{\mathrm{ref},i}$ is the model-based torque required to follow the reference trajectory, $[\,\cdot\,]_+$ denotes the positive part, and $k_{\mathrm{aan}}(t,e_i)\in[0,1]$ is an adaptive gain that grows with tracking error $e_i=q_{i,\mathrm{ref}}-q_i$ and decays with successful tracking. Concretely, we use
\begin{equation}
k_{\mathrm{aan}}(t,e_i)=\mathrm{sat}_{[0,1]}\!\left(k_0+k_e\,|e_i|-k_s\right),
\end{equation}
where $k_0$ is a small baseline, $k_e>0$ is an error-dependent rise rate, and $k_s>0$ is a forgetting term that decays the gain when tracking is consistent. This produces the desired AAN behavior: the robot does not assist as long as the user can follow the trajectory, and ramps up assistance only when needed, in line with the principles articulated by Reinkensmeyer and colleagues~\cite{cai2006implications,marchal2009review}.

\subsection{Safety Supervision}

A safety supervisor enforces:
\begin{itemize}
\item per-joint angle and velocity limits derived from the optimized workspace and clinician-prescribed range of motion;
\item per-motor current limits below the XM430-W350-R stall current;
\item soft-start and soft-stop ramps at the start and end of every trajectory;
\item online monitoring of $\kappa(\mathbf{J}_r)$ via \eqref{eq:jacobian}, which scales velocity commands down as the platform approaches singular configurations;
\item dropout pause when IMU or gait-mat data are missing or stale; and
\item a hardware emergency-stop input that opens the actuator power line.
\end{itemize}

\section{Embedded System and Sensor Architecture}
\label{sec:hardware}

\subsection{Master Controller and Actuator Bus}

The on-device computer is a Teensy~4.1, an ARM Cortex-M7 microcontroller running at 600\,MHz that provides deterministic, low-latency execution suitable for medical-grade closed-loop control. The Teensy~4.1 hosts a 1~kHz control loop that performs (i) IMU acquisition, (ii) numerical IK, (iii) AAN torque computation, (iv) safety checks, and (v) actuator command transmission, with sufficient headroom for online estimation routines. A 1~kHz loop rate is consistent with prior practice in ankle-exoskeleton control where stable force-feedback loops are required~\cite{zhang2015torque,jackson2019heuristic}.

The actuators communicate with the master over a single RS-485 daisy-chain bus, which simplifies wiring and reduces the cable mass on the limb. The XM430-W350-R operates in the manufacturer's current-based position-control mode, in which the user commands a position setpoint and a current saturation, while the actuator returns position, velocity, and current measurements~\cite{robotisxm430}. The position encoding is
\begin{equation}
\mathrm{tick}=2048+\frac{\theta_{\deg}}{0.087912},
\end{equation}
giving a resolution of approximately $0.088^{\circ}$ per tick across the full $0$--$4095$ tick range, sufficient for the angular resolutions required in ankle rehabilitation. Figure~\ref{fig:hardware} shows the prototype electronics stack used for early integration of the master, IMU, and RS-485 bus.

\begin{figure}[!t]
\centering
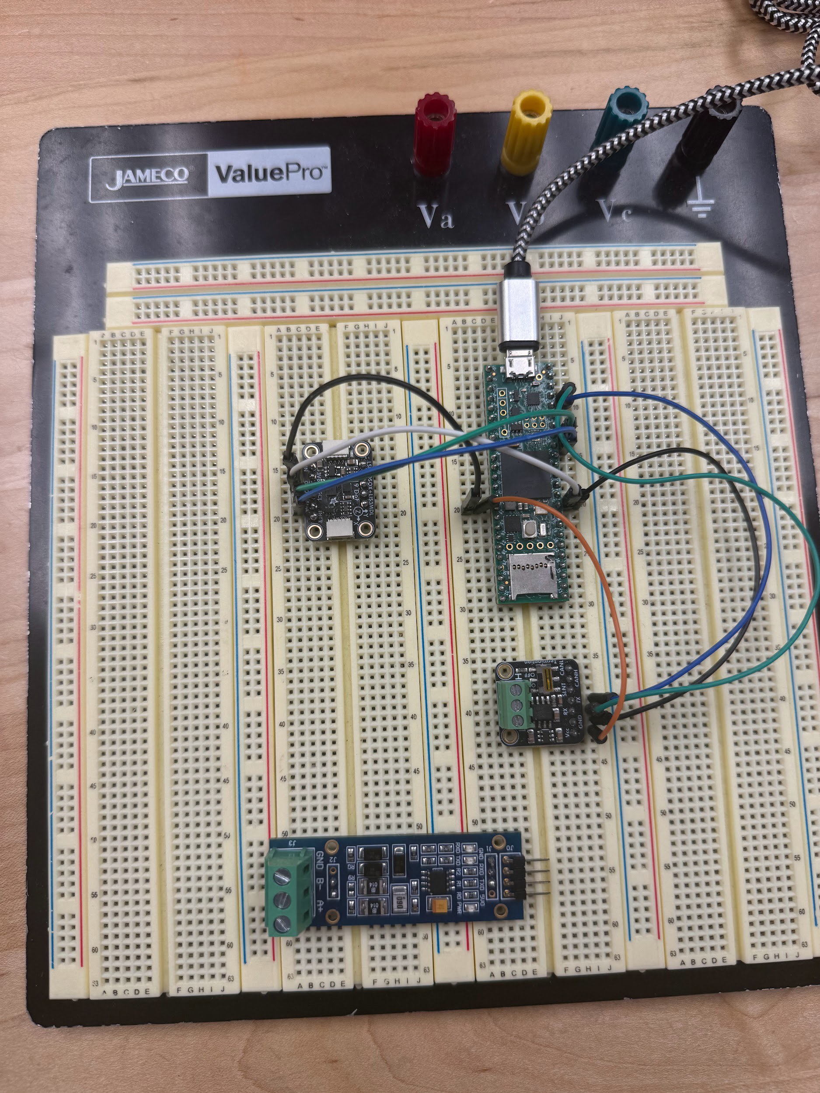
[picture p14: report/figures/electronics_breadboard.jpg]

\caption{Prototype electronics stack on a breadboard for early integration. A Teensy~4.1 master (center) talks to an IMU breakout (left) for shank/foot orientation and a TTL-to-RS-485 transceiver (bottom) that bridges to the daisy-chained Dynamixel XM430-W350-R actuator bus. The actuator current measurement returned over the same bus feeds the sensorless torque estimator of \eqref{eq:tau_ext}.}
\label{fig:hardware}
\end{figure}

\subsection{Sensor Suite}

Three classes of sensors are integrated:
\begin{itemize}
\item \textbf{Motor encoders.} Each XM430-W350-R reports relative joint angle, velocity, and current at the 1~kHz loop rate. The current measurement is used directly in the AAN torque estimator \eqref{eq:tau_ext}.
\item \textbf{Inertial measurement units.} Two IMUs are mounted on the lower limb. One is fixed to the patient's tibia (shank), and the other to the dorsum of the foot or directly to the moving platform. While the encoders measure relative joint angles, the dual-IMU arrangement provides absolute orientation referenced to gravity, which is essential both for the AAN reference and for cross-validating the IK output~\cite{yue2018wearable}.
\item \textbf{Gait mat and external pose tracker.} A laboratory gait mat measures stance time, plantar pressure distribution, and the CoP trajectory, mirroring the instrumented-shoe pipeline of Prado \emph{et al.}~\cite{prado2020fog} and Paydarfar \emph{et al.}~\cite{paydarfar2020rnn}. An HTC Vive tracker is used as a high-precision external reference for foot-plate orientation during calibration of the kinematic parameters and for periodic re-validation.
\end{itemize}

\subsection{Wearable Form Factor}

The 3D-printed prototype provides a functional but coarse human interface. Planned hardware iteration adds a foam insole and soft padding inside the foot brace and around the base ring strap to reduce localized skin pressure during extended training sessions. A low-profile cable management strategy following~\cite{yandell2019profile} routes the actuator wiring along the medial side of the limb to avoid interference with footwear or orthoses.

\section{Open-Source Design and Validation Pipeline}
\label{sec:opensource}

To support reproducibility and to lower the barrier to porting this work to other hardware, the device's full software stack is publicly released under the MIT license. The release is organized as a single ROS\,2 \emph{ament\_python} package and bundles four logically distinct layers: (i) a kinematic core that implements the numerical inverse-kinematic (IK) solver of Section~\ref{sec:kinematics}; (ii) a robot description layer (URDF and a lightweight Xacro variant) together with the visual and collision meshes; (iii) a ROS\,2 layer that exposes the kinematic core as a node and provides four launch files for visualization, scripted-trajectory playback, interactive pose commands, and Gazebo bring-up; and (iv) a dependency-free scripting layer that reproduces the closed-loop demo, mines kinematic candidates from a SolidWorks STEP export, and bootstraps a first-pass IK parameter file. The same kinematic core is shared across all entry points, so behaviour is consistent between pure-Python execution, RViz visualization, Gazebo simulation, and the eventual hardware bus.

\subsection{Parallel Inverse-Kinematics Solver}

The IK solver implements the numerical formulation of Section~\ref{sec:kinematics}, summarised in Algorithm~\ref{alg:ik}. For a requested foot-plate orientation $R_{BF}$ the solver computes each platform-side point $\mathbf{P}_i^B$, then for each leg evaluates the scalar residual $f_i(q_i)$ from \eqref{eq:leg-constraint} on a coarse motor-angle bracket. Inside any bracket where $f_i$ changes sign, a bisection root finder locates the active root, and the root closest to the previous control cycle is retained to enforce branch continuity. The solver depends only on the Python standard library, which is what allows the same code to run inside a ROS\,2 node, inside a CLI demo on a host laptop, and---once a Dynamixel SDK shim is added---inside the embedded loop on the Teensy~4.1.

\begin{algorithm}[!t]
\caption{Per-cycle parallel IK solver}
\label{alg:ik}
\begin{algorithmic}[1]
\REQUIRE foot-plate orientation $(\mathrm{roll},\mathrm{pitch},\mathrm{yaw})$, prior motor angles $\boldsymbol{q}^{-}$, geometry $\{\mathbf{B}_i^B,\mathbf{u}_i^B,\mathbf{P}_i^F,L_i\}_{i=1}^{3}$
\ENSURE motor angles $\boldsymbol{q}=(q_1,q_2,q_3)$
\STATE compute $R_{BF}=R_z(\mathrm{yaw})\,R_y(\mathrm{pitch})\,R_x(\mathrm{roll})$
\FOR{each leg $i\in\{1,2,3\}$}
  \STATE $\mathbf{P}_i^B \gets R_{BF}\,\mathbf{P}_i^F$
  \STATE evaluate residual $f_i(q)=\|\mathbf{P}_i^B-\mathbf{A}_i^B(q)\|-L_i$ on a coarse grid of $q$
  \STATE pick the bracket containing $q^{-}_i$ with $\mathrm{sign}(f_i)$ change
  \STATE $q_i \gets$ bisection on $f_i$ inside that bracket
\ENDFOR
\STATE \textbf{return} $\boldsymbol{q}$
\end{algorithmic}
\end{algorithm}

\subsection{ROS\,2 Layer and Gazebo Verification}

The ROS\,2 package wraps the kinematic core into a standard \emph{robot\_state\_publisher} pipeline. Four launch files cover the typical use cases: a static-URDF visualization in RViz; a scripted ankle-rehab trajectory replayed through a JointState player; an interactive node that converts (roll, pitch, yaw) parameters into the three motor angles via Algorithm~\ref{alg:ik} and republishes the resulting JointState at a configurable rate; and a Gazebo bring-up that loads the same URDF together with a default world. All four entries share one URDF / Xacro source and one Python kinematic core, so adding a new motion is a one-file change.

The URDF is also smoke-tested inside Gazebo. The \emph{Apply Force and Torque} dialog is used to inject pure forces and torques of varying magnitudes at the centre of mass and at off-centre Cartesian application points on each link, sweeping a representative grid. We log resulting platform poses, link inertial readings, and any mesh-collision penetrations. So far this sweep has not surfaced abnormal drifts or NaN inertias, confirming that the joint axes, inertial entries, and mesh references exported from SolidWorks are physically consistent. Figure~\ref{fig:gazebo-ft} shows the test in progress with a $\sim 100$~Nm pure torque applied to the proximal link.

\begin{figure}[!t]
\centering
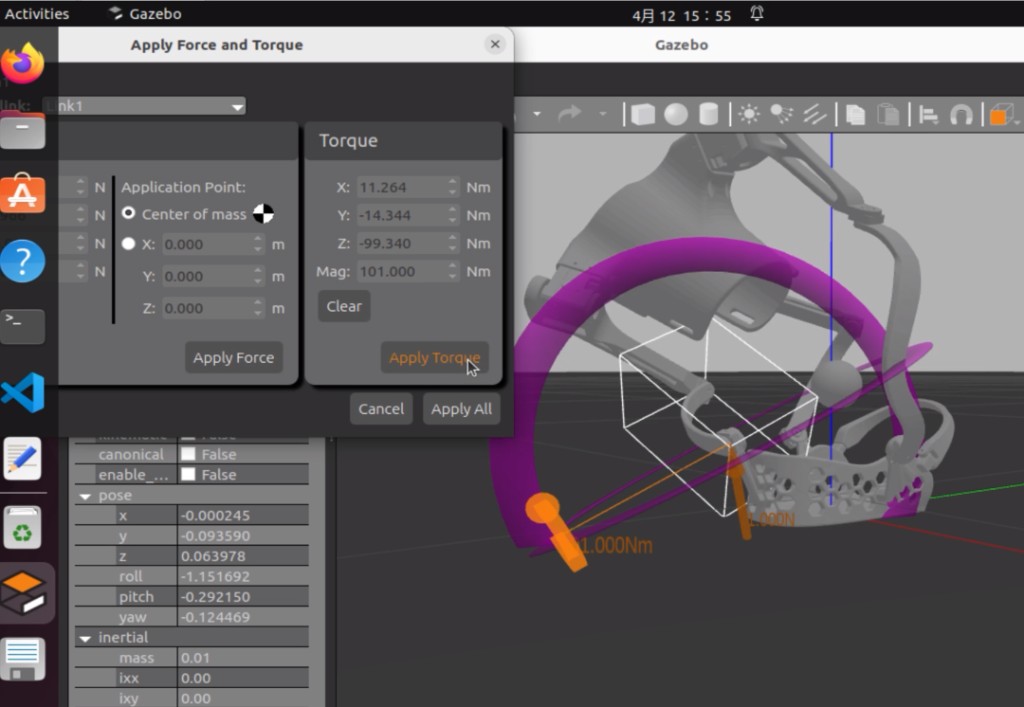
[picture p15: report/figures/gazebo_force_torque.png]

\caption{Gazebo verification of the URDF / Xacro model. The \emph{Apply Force and Torque} dialog is being used to inject a 101~Nm pure torque (with components $T_x{=}11.3$, $T_y{=}{-}14.3$, $T_z{=}{-}99.3$~Nm) on the proximal link at its centre of mass. The purple arrow in the viewport is Gazebo's visualization of the applied torque, the small wireframe widget marks the application point, and the lower-left property panel reports the link pose (roll, pitch, yaw of $-1.152$, $-0.292$, $-0.124$~rad) together with the inertial entries that the URDF defines. Both are cross-checked against the SolidWorks export.}
\label{fig:gazebo-ft}
\end{figure}

\subsection{Closed-Loop Tracking Demo}

The closed-loop tracking demo, summarised in Algorithm~\ref{alg:loop}, exercises the IK solver inside a slow, low-amplitude reference trajectory on the URDF model, without requiring Gazebo, ROS\,2, or hardware. At each control cycle it generates a clinically motivated reference pose---combined sinusoidal dorsiflexion / plantarflexion at $\pm 12^{\circ}$ and inversion / eversion at $\pm 6^{\circ}$ at $0.05$~Hz, with a $3$~s soft start---runs Algorithm~\ref{alg:ik} to obtain the three motor commands, applies the safety supervisor's torque ($1.2$~Nm) and velocity ($0.8$~rad/s) caps on the per-cycle increment, and updates a virtual actuator state. Per-cycle feedback (commanded vs.\ measured joint angles, residual tracking error, and Dynamixel goal ticks via the encoding of Section~\ref{sec:hardware}) is logged to a CSV file. A screen capture of the demo running against the URDF model is included in the repository (under \emph{media/}, $\sim 25$~MB).

\begin{algorithm}[!t]
\caption{Closed-loop ankle-rehab tracking demo}
\label{alg:loop}
\begin{algorithmic}[1]
\REQUIRE URDF, amplitudes $A_p,A_r$, frequency $f$, soft-start $T_s$, torque cap $\tau_{\max}$, velocity cap $\dot{q}_{\max}$
\STATE parse URDF; identify $(j_1,j_4,j_6)$ as the three Dynamixel actuators
\STATE $\boldsymbol{q}\gets\mathbf{0}$;\ \ $t\gets 0$
\WHILE{run}
  \STATE $\sigma(t)\gets\min(t/T_s,\,1)$ \hfill\COMMENT{soft-start ramp}
  \STATE $\mathrm{pitch}\gets \sigma(t)\,A_p\sin(2\pi f t)$
  \STATE $\mathrm{roll} \gets \sigma(t)\,A_r\sin(2\pi f t)$
  \STATE $\boldsymbol{q}^{\mathrm{ref}}\gets$ \textsc{ParallelIK}(roll, pitch, $0$)
  \STATE $\Delta\boldsymbol{q}\gets$ \textsc{Clamp}($\boldsymbol{q}^{\mathrm{ref}}-\boldsymbol{q}$,\ $\dot{q}_{\max}\Delta t$)
  \STATE $\boldsymbol{\tau}\gets$ \textsc{Clamp}(controller$(\Delta\boldsymbol{q})$,\ $\tau_{\max}$)
  \STATE $\boldsymbol{q}\gets\boldsymbol{q}+\Delta\boldsymbol{q}$ \hfill\COMMENT{advance virtual actuator state}
  \STATE log $(t,\boldsymbol{q}^{\mathrm{ref}},\boldsymbol{q},\boldsymbol{\tau},\,\textsc{ToTicks}(\boldsymbol{q}))$
  \STATE $t\gets t+\Delta t$
\ENDWHILE
\end{algorithmic}
\end{algorithm}

\subsection{Reproducibility and Extension}

A new user reproduces the simulation results in three steps: (i) clone the repository; (ii) run the closed-loop demo as a standalone Python script for an end-to-end sanity check; and (iii) build the package in a ROS\,2 workspace (Humble or later) and launch the interactive parallel-IK pose demo for live RViz feedback. The geometry of the legs and the motor zero offsets are isolated in JSON parameter templates, so porting the same pipeline to a different physical prototype does not require touching any Python code.

\section{Experimental Methodology}
\label{sec:experiments}

This section defines the experimental protocol used to evaluate the device. Three categories of active-rehabilitation experiments and one passive transfer-effect experiment share a common set of quantitative metrics and a common analysis pipeline. The reference clinical practice that the device is designed to standardize and complement is illustrated in Fig.~\ref{fig:manual-therapy}: a clinician's manual mobilization of the talocrural, subtalar, and distal tibiofibular joints in both anterior--posterior and posterior--anterior directions. By replicating these mobilization patterns under quantitative control, the proposed device aims to reduce inter-clinician variability and produce dose-controlled therapy.

\begin{figure}[!t]
\centering
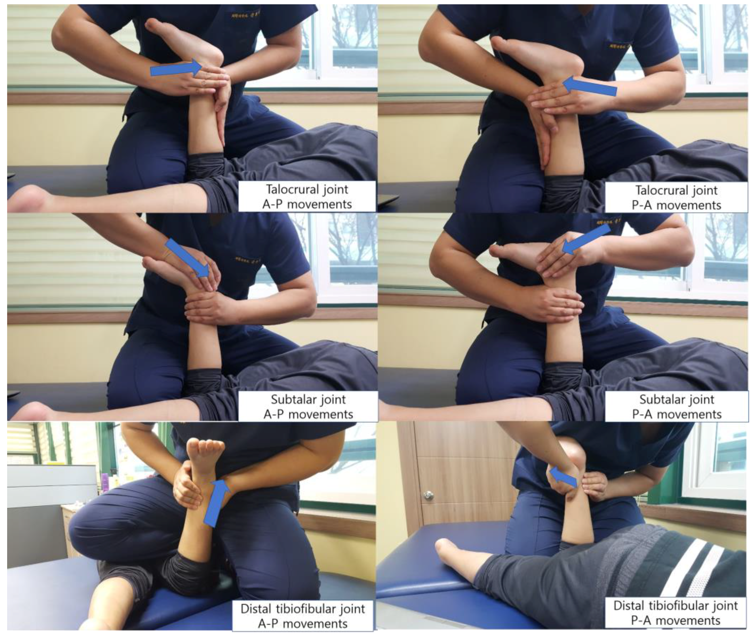
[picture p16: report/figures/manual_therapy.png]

\caption{Clinical reference: manual ankle mobilization of the talocrural, subtalar, and distal tibiofibular joints in both A--P and P--A directions, as performed by a physical therapist. Therapist-driven manual therapy of this type is the dominant standard of care, but it is highly dependent on clinician experience and provides only qualitative dosing. The proposed robotic device targets the same biomechanical motions while providing quantitative trajectory tracking, interaction-torque estimation, and outcome metrics. Image adapted from clinical rehabilitation literature.}
\label{fig:manual-therapy}
\end{figure}

\subsection{Quantitative Metrics}

The primary metrics, drawn from the rehabilitation-robotics literature, are:
\begin{itemize}
\item \textbf{Limb Symmetry Index (LSI)}, the ratio of an outcome variable measured on the affected versus the unaffected limb, computed for peak ankle range of motion (ROM), peak plantar pressure, and stance time. LSI is the ``north-star'' clinical metric: scores in the 90--110\% band are conventionally regarded as restored symmetry~\cite{hidayah2020calex}.
\item \textbf{Jerk}, the time derivative of acceleration, computed from the foot-plate IMU and used as a smoothness indicator. Smoother trajectories correlate with motor-skill consolidation~\cite{marchal2009review}.
\item \textbf{Interaction torque} $\tau_{\mathrm{int}}$ between device and patient, estimated via the AAN torque estimator \eqref{eq:tau_ext} and reported in Newton-meters per gait cycle.
\item \textbf{Center of Pressure (CoP)} from the gait mat, reported for both static stance and dynamic gait cycles.
\item \textbf{Human-contribution ratio} $\eta_h=\tau_{\mathrm{ext}}/(\tau_{\mathrm{ext}}+\tau_{\mathrm{assist}})$, indicating the fraction of total joint torque produced by the patient under AAN.
\end{itemize}

\subsection{Subject Cohort and Controlled-Deficit Induction}

Initial subjects are three healthy team members. To create a controlled and ethically tractable functional deficit, we induce a \emph{simulated foot-drop} condition by either (a) attaching a small calibrated weight near the toe, increasing the swing-phase plantarflexion moment and forcing the participant to compensate, or (b) commanding a downward (plantarflexion) bias torque on the device's distal limb, which the participant must overcome to achieve dorsiflexion. Both methods are reversible, do not require an IRB-regulated patient population, and produce a measurable LSI deviation that mirrors clinical foot-drop without exposing impaired participants. A baseline (no-deficit, no-device) condition and a deficit-only (no-device) condition are also recorded for each subject to establish within-subject baselines.

\subsection{Experiment 1: Simulated-Impairment Recovery}

\textbf{Hypothesis.} AAN training corrects the abnormal gait pattern induced by the simulated deficit, with measurable improvement in LSI and reduction of compensatory motions (e.g., hip hiking).

\textbf{Protocol.} Each subject completes four conditions: baseline walking; deficit-only walking; deficit walking with the device in transparent mode; and deficit walking with the device in AAN mode. Each condition consists of a 5-minute walking trial on the gait mat at a self-selected speed. The peak ankle ROM, plantar-pressure peak, stance time, hip joint excursion, and IMU-derived foot-clearance metric are extracted from the central 90~s of each trial.

\textbf{Outcome.} A successful outcome is an LSI improvement from $\sim 80\%$ in the deficit-only condition toward $\sim 95\%$ in the AAN condition, accompanied by a measurable reduction in hip-hiking range, in line with the kind of changes reported by Hidayah \emph{et al.}~\cite{hidayah2020calex} for stroke participants under cable-driven exoskeleton training.

\subsection{Experiment 2: Transparency Evaluation}

\textbf{Hypothesis.} Under near-zero-impedance control, the device does not appreciably alter natural ankle kinematics or impose significant interaction torques on the user.

\textbf{Protocol.} The controller is placed in a transparency mode that suppresses all assistance and applies only a low-gain damping term sufficient to suppress motor friction. Each subject walks 5~minutes barefoot on the gait mat (Condition~A) and 5~minutes wearing the device in transparent mode (Condition~B). The IMU-derived ankle angle trajectory and the gait-mat-derived CoP trajectory are compared between conditions using stride-normalized signals.

\textbf{Outcome.} The system is considered approximately transparent if the inter-condition similarity satisfies $R^2 > 0.95$ on the stride-normalized ankle angle and $|\tau_{\mathrm{int}}| \to 0$ throughout the gait cycle, in line with the transparency criteria reported in~\cite{galle2013adaptation,jackson2019heuristic}.

\subsection{Experiment 3: Active Participation under AAN}

\textbf{Hypothesis.} Under AAN control, the human-contribution ratio $\eta_h$ increases across training sessions while the jerk-based smoothness index remains within a stability band, indicating that AAN promotes voluntary effort without destabilizing motion.

\textbf{Protocol.} Each subject completes five 10-minute AAN training sessions on consecutive days. Within each session, $\eta_h$ and the per-stride jerk are computed and reported as session-mean values with 95\% confidence intervals. A linear mixed-effects model is used to assess the across-session trend, with subject as a random effect.

\textbf{Outcome.} A rising $\eta_h$ and a stable jerk profile would indicate that the AAN gain is correctly modulating assistance: enough to permit successful trajectory completion early in training, but progressively less as the user re-acquires the skill, consistent with the motor-learning theory underlying AAN~\cite{cai2006implications,marchal2009review}.

\subsection{Experiment 4: Passive Transfer Effect}

\textbf{Hypothesis.} A short bout of passive (CPM) training on the device, with enhanced dorsiflexion amplitude, produces a short-term carryover in overground gait, manifested as an increase in step length and a forward shift of the CoP.

\textbf{Protocol.} Each subject performs a baseline overground walking trial; then 10~minutes of seated, passive CPM training on the device with prescribed dorsiflexion amplitude; and finally a post-training overground walking trial. Step length and CoP are extracted from the gait mat in both walking trials. Within-subject pre/post differences are tested using paired $t$-tests with Bonferroni correction.

\textbf{Outcome.} A consistent post-training increase in step length and forward CoP shift would indicate that the device modulates the patient's neural control strategy beyond the immediate biomechanical effect of wearing it, mirroring the transfer-effect framework used in~\cite{galle2013adaptation,gordon2007learning}.

\subsection{Sensing Pipeline and Data Synchronization}

All sensor streams are time-stamped on the Teensy~4.1 with a common monotonic clock. IMU data are sampled at 200~Hz, motor data at the controller's 1~kHz loop rate (down-sampled for logging), and the gait-mat events are received over Ethernet at the mat's native frame rate. Data are streamed to a host laptop for off-line analysis. Per-stride segmentation uses heel-strike events from the foot IMU, validated against gait-mat contacts. Activity classification baselines following~\cite{paydarfar2020rnn} are reserved for future work.

\subsection{Statistical Analysis}

Group-level statistics are reported as mean $\pm$ standard deviation, with 95\% confidence intervals computed by bootstrap resampling ($n=10000$). Within-subject paired comparisons use paired $t$-tests when normality is supported by a Shapiro-Wilk test; otherwise, Wilcoxon signed-rank tests are used. Multiple-comparison corrections are applied at the experiment level using the Bonferroni-Holm procedure. Across-session trends are analyzed using linear mixed-effects models with subject as a random effect.

\section{Implementation Status}
\label{sec:results}

Table~\ref{tab:goals} summarizes the status of the research goals proposed in this report. Five of the six goals are complete and reproducible from the open-source repository introduced in Section~\ref{sec:opensource}; the remaining goal---hardware integration with a real Dynamixel bus and the human-subject experiments described in Section~\ref{sec:experiments}---is in progress.

\begin{table}[!t]
\centering
\caption{Status of proposed goals.}
\label{tab:goals}
\begin{tabular}{p{0.40\linewidth} p{0.20\linewidth} p{0.30\linewidth}}
\toprule
\textbf{Goal} & \textbf{Status} & \textbf{Outcome}\\
\midrule
Wearable 3-RRR mechanism with structurally favourable link ratio & Completed & $l_2/l_1\approx 1.15$, isotropy +20\%\\
Closed-form and numerical IK & Completed & Sec.~\ref{sec:kinematics}\\
Joint-to-actuator mapping ($\theta_i \to$ XM430) & Completed & Sec.~\ref{sec:hardware}\\
Open-source ROS\,2 / Gazebo pipeline & Completed & Sec.~\ref{sec:opensource}, MIT-licensed release\\
AAN control formulation & Proposed & Eq.~\eqref{eq:tau_ext}--\eqref{eq:tau_assist}\\
Embedded system architecture & Completed & Teensy~4.1 + RS-485 + dual IMU + gait mat\\
Hardware integration and experiments & In progress & Sec.~\ref{sec:experiments}\\
\bottomrule
\end{tabular}
\end{table}

\section{Conclusion and Future Work}
\label{sec:conclusion}

This report extends our prior 3-RRR ankle rehabilitation robot~\cite{zhang2025rehab} from a CAD-and-prototype snapshot into a reproducible research platform. Three concrete contributions are delivered. First, a wearable 3-RRR SPM embodiment with a structurally favourable link ratio ($l_2/l_1\approx 1.15$) improves the global rotational-Jacobian isotropy by approximately 20\% relative to a naive 1:1 design and pushes parallel singularities toward the workspace boundary. Second, analytical and numerical inverse-kinematic formulations map a clinically meaningful (roll, pitch, yaw) command to the three actuated motor angles in a form suitable for real-time execution on a Teensy~4.1 platform driving Dynamixel XM430-W350-R smart actuators. Third, a complete open-source design and validation pipeline---a ROS\,2 \emph{ament\_python} package with a URDF / Xacro verified in Gazebo, a parallel-IK solver, an interactive pose demo, and a dependency-free closed-loop tracking demo with a recorded video clip---is released under an MIT license at \url{https://github.com/YufeiZhang0601/wearable-3rrr-ankle-rehab}, lowering the barrier for other groups to extend or replicate this work on their own physical prototypes. The proposed AAN control law and the multi-modal sensing protocol provide the framework on which planned hardware-in-the-loop experiments will be built.

Future work falls into three lines. \emph{Modeling}: replace the single-center spherical assumption with a dual-axis non-concentric ankle model that better matches biomechanics, and integrate the Lagrangian dynamic model into a model-based feedforward layer. \emph{Control and software}: instantiate the proposed AAN gain schedule on a real Dynamixel bus inside the open-source pipeline, extend it with fuzzy-logic impedance and gait-phase switching, and incorporate online Jacobian-condition-number monitoring \eqref{eq:jacobian} as an adaptive velocity scaler within the safety supervisor. \emph{Experiments}: complete the planned protocol with healthy subjects, then plan an IRB-approved human-subject study to evaluate alignment, comfort, and therapeutic efficacy in patient populations with foot drop, post-stroke ankle weakness, or chronic ankle instability.

\section*{Acknowledgment}

The author gratefully acknowledges Prof.\ Sunil K.\ Agrawal for his guidance throughout this AMR research project, and the team members and collaborators who contributed to the design, modeling, and evaluation of the proposed system.

\begin{thebibliography}{99}

\bibitem{zhang2025rehab} S.~Zhang, Y.~Zhang, J.~Lyu, and S.~K.~Agrawal, ``From structural design to dynamics modeling: Control-oriented development of a 3-RRR parallel ankle rehabilitation robot,'' \emph{arXiv preprint arXiv:2505.13762}, 2025.

\bibitem{gosselin1989optimum} C.~M.~Gosselin and J.~Angeles, ``The optimum kinematic design of a spherical three-degree-of-freedom parallel manipulator,'' \emph{ASME J.~Mech., Transm., Autom.~Des.}, vol.~111, no.~2, pp.~202--207, 1989.

\bibitem{merlet2006jacobian} J.-P.~Merlet, ``Jacobian, manipulability, condition number, and accuracy of parallel robots,'' \emph{Int.~J.~Robot.~Res.}, vol.~25, no.~6, pp.~557--571, 2006.

\bibitem{saheb2021math} H.~S.~Shaik and G.~S.~Babu, ``Mathematical modeling and kinematic analysis of 3-RRR planar parallel manipulator,'' \emph{EAI Endorsed Transactions on Energy Web}, vol.~8, no.~35, e9, 2021.

\bibitem{wu2019designandkinematic} G.~Wu and S.~Bai, ``Design and kinematic analysis of a 3-RRR spherical parallel manipulator with reconfigurable four-bar linkages,'' \emph{Robot.~Comput.~Integr.~Manuf.}, vol.~56, pp.~55--65, 2019.

\bibitem{he2021spindle} P.~He \emph{et al.}, ``A novel 3-RRR spherical parallel instrument for daily living emulation (SPINDLE) for functional rehabilitation of patients with stroke,'' \emph{Int.~J.~Adv.~Robot.~Syst.}, vol.~18, no.~3, 2021.

\bibitem{sadeqi2017hip} S.~Sadeqi, S.~P.~Bourgeois, E.~J.~Park, and S.~Arzanpour, ``Design and performance analysis of a 3-RRR spherical parallel manipulator for hip exoskeleton applications,'' \emph{J.~Rehabil.~Assist.~Technol.~Eng.}, vol.~4, 2017.

\bibitem{dollar2008lower} A.~M.~Dollar and H.~Herr, ``Lower extremity exoskeletons and active orthoses: Challenges and state-of-the-art,'' \emph{IEEE Trans.~Robot.}, vol.~24, no.~1, pp.~144--158, 2008.

\bibitem{sale2012robot} P.~Sale, M.~Franceschini, A.~Waldner, S.~Hesse \emph{et al.}, ``Use of the robot assisted gait therapy in rehabilitation of patients with stroke and spinal cord injury,'' \emph{Eur.~J.~Phys.~Rehabil.~Med.}, vol.~48, no.~1, pp.~111--121, 2012.

\bibitem{dong2021parallelankle} M.~Dong \emph{et al.}, ``State of the art in parallel ankle rehabilitation robot: A systematic review,'' \emph{J.~NeuroEng.~Rehabil.}, vol.~18, no.~1, 2021.

\bibitem{cai2006implications} L.~L.~Cai \emph{et al.}, ``Implications of assist-as-needed robotic step training after a complete spinal cord injury on intrinsic strategies of motor learning,'' \emph{J.~Neurosci.}, vol.~26, no.~41, pp.~10564--10568, 2006.

\bibitem{marchal2009review} L.~Marchal-Crespo and D.~J.~Reinkensmeyer, ``Review of control strategies for robotic movement training after neurologic injury,'' \emph{J.~NeuroEng.~Rehabil.}, vol.~6, no.~20, 2009.

\bibitem{prado2020fog} A.~Prado, K.~Kwei, N.~Vanegas-Arroyave, and S.~K.~Agrawal, ``Identification of freezing of gait in Parkinson's patients using instrumented shoes and artificial neural networks,'' in \emph{Proc.~IEEE RAS/EMBS Int.~Conf.~Biomed.~Robot.~Biomechatronics (BioRob)}, 2020, pp.~68--73.

\bibitem{hidayah2020calex} R.~Hidayah, L.~Bishop, X.~Jin, S.~Chamarthy, J.~Stein, and S.~K.~Agrawal, ``Gait adaptation using a cable-driven active leg exoskeleton (C-ALEX) with post-stroke participants,'' \emph{IEEE Trans.~Neural Syst.~Rehabil.~Eng.}, vol.~28, no.~9, pp.~1984--1993, Sept.~2020.

\bibitem{paydarfar2020rnn} A.~J.~Paydarfar, A.~Prado, and S.~K.~Agrawal, ``Human activity recognition using recurrent neural network classifiers on raw signals from insole piezoresistors,'' in \emph{Proc.~IEEE RAS/EMBS Int.~Conf.~Biomed.~Robot.~Biomechatronics (BioRob)}, 2020, pp.~916--921.

\bibitem{tomc2025actuator} M.~Tomc, M.~Zadravec, A.~Olen\v{s}ek, and Z.~Matja\v{c}i\'c, ``Actuator- and control-less ankle exoskeleton for push-off assistance during treadmill walking: A proof-of-concept study,'' in \emph{Proc.~Int.~Conf.~Rehabil.~Robot.~(ICORR)}, 2025, pp.~681--686.

\bibitem{hybart2022emg} R.~L.~Hybart and D.~P.~Ferris, ``Preliminary validation of proportional myoelectric control of a commercially available robotic ankle exoskeleton,'' in \emph{Proc.~Int.~Conf.~Rehabil.~Robot.~(ICORR)}, 2022, pp.~1--5.

\bibitem{galle2013adaptation} S.~Galle, P.~Malcolm, W.~Derave, and D.~De Clercq, ``Adaptation to walking with an exoskeleton that assists ankle extension,'' \emph{Gait \& Posture}, vol.~38, no.~3, pp.~495--499, 2013.

\bibitem{jackson2019heuristic} R.~W.~Jackson and S.~H.~Collins, ``Heuristic-based ankle exoskeleton control for co-adaptive assistance of human locomotion,'' \emph{IEEE Trans.~Neural Syst.~Rehabil.~Eng.}, vol.~27, no.~10, pp.~2059--2069, Oct.~2019.

\bibitem{zhang2015torque} J.~Zhang, C.~C.~Cheah, and S.~H.~Collins, ``Experimental comparison of torque control methods on an ankle exoskeleton during human walking,'' in \emph{Proc.~IEEE Int.~Conf.~Robot.~Autom.~(ICRA)}, 2015, pp.~5584--5589.

\bibitem{gordon2007learning} K.~E.~Gordon and D.~P.~Ferris, ``Learning to walk with a robotic ankle exoskeleton,'' \emph{J.~Biomech.}, vol.~40, no.~12, pp.~2636--2644, 2007.

\bibitem{pan2025bowden} X.~Pan, J.~Mi, T.~Yu, S.~Chu, and P.~Zhu, ``Design of ankle exoskeleton based on closed-loop Bowden cable,'' in \emph{Proc.~IEEE Int.~Conf.~Electr., Autom.~Comput.~Eng.~(ICEACE)}, 2025, pp.~244--248.

\bibitem{orekhov2021untethered} G.~Orekhov, Y.~Fang, C.~F.~Cuddeback \emph{et al.}, ``Usability and performance validation of an ultra-lightweight and versatile untethered robotic ankle exoskeleton,'' \emph{J.~NeuroEng.~Rehabil.}, vol.~18, no.~163, 2021.

\bibitem{fang2022incline} Y.~Fang and Z.~F.~Lerner, ``How ankle exoskeleton assistance affects the mechanics of incline walking and stair ascent in cerebral palsy,'' in \emph{Proc.~Int.~Conf.~Rehabil.~Robot.~(ICORR)}, 2022, pp.~1--6.

\bibitem{tomc2022treadmill} M.~Tomc and Z.~Matja\v{c}i\'c, ``Harnessing energy of a treadmill for push-off assistance during walking: In-silico feasibility study,'' \emph{Front.~Bioeng.~Biotechnol.}, vol.~10, art.~832087, 2022.

\bibitem{perez2024modeling} U.~P\'erez-Flores, A.~D.~Palomino-Merino, J.~R.~L\'opez-Guti\'errez, and S.~Vergara-Limon, ``Modeling and control of ankle exoskeleton,'' in \emph{Proc.~Int.~Conf.~Electr.~Eng., Comput.~Sci.~Autom.~Control (CCE)}, 2024, pp.~1--6.

\bibitem{camardo2025passive} M.~Camardo \emph{et al.}, ``Design evaluation of a passive ankle exoskeleton for gait training,'' in \emph{Proc.~Int.~Conf.~Rehabil.~Robot.~(ICORR)}, 2025, pp.~1444--1448.

\bibitem{yandell2019profile} M.~B.~Yandell, J.~R.~Tacca, and K.~E.~Zelik, ``Design of a low profile, unpowered ankle exoskeleton that fits under clothes: Overcoming practical barriers to widespread societal adoption,'' \emph{IEEE Trans.~Neural Syst.~Rehabil.~Eng.}, vol.~27, no.~4, pp.~712--723, Apr.~2019.

\bibitem{peng2023bidirectional} Y.~Peng, J.~Chen, L.~Wang, J.~Han, and J.~Zhang, ``Design and evaluation of a bidirectional ankle exoskeleton system,'' in \emph{Proc.~Youth Acad.~Annu.~Conf.~CAA (YAC)}, 2023, pp.~481--485.

\bibitem{zhang2022variable} J.~Zhang, W.~Dong, C.~Xiong, and Q.~Zhang, ``Mechanical design and experimental validation of a variable stiffness ankle exoskeleton,'' in \emph{Proc.~Int.~Conf.~Adv.~Robot.~Mechatronics (ICARM)}, 2022, pp.~459--464.

\bibitem{yue2018wearable} C.~Yue, X.~Lin, X.~Zhang, J.~Qiu, and H.~Cheng, ``Design and performance evaluation of a wearable sensing system for lower-limb exoskeleton,'' \emph{Appl.~Bionics Biomech.}, vol.~2018, art.~8610458, 2018.

\bibitem{robotisxm430} ROBOTIS, ``Dynamixel XM430-W350-R e-manual,'' [Online]. Available: \url{https://emanual.robotis.com/docs/en/dxl/x/xm430-w350/}, accessed May~2026.

\end{thebibliography}

\end{document}

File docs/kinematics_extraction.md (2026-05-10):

# RH1 STEP Kinematics Extraction

This workflow turns the SolidWorks STEP assembly into a short list of geometry
candidates that can be confirmed and copied into an IK parameter file.

## Generate candidates

From the repository root:

```bash
python3 scripts/extract_step_kinematics.py assem_v3.STEP
```

On Windows PowerShell:

```powershell
python scripts\extract_step_kinematics.py assem_v3.STEP
```

The script writes:

```text
demo_output/step_kinematics_candidates.json
demo_output/step_kinematics_candidates.md
```

For the current `assem_v3.STEP`, the strongest unverified actuator-axis
candidates have also been copied into:

```text
params/kinematic_params.candidate.yaml
```

Treat that file as a starting point, not as a validated IK model.

## What to confirm

The STEP file contains many circular holes and shafts, so the script reports
candidates instead of pretending to know the mechanism. Confirm these values in
SolidWorks or by visual inspection:

- `joint1`, `joint4`, `joint6`: the three XM430 output axes.
- `p1`, `p2`, `p3`: the three moving-platform connection axes/points on the
  foot plate.
- `ankle_center_base_mm`: the intended spherical center of rotation.
- `zero_angle_rad`: the motor angle offset when the CAD assembly is in the
  neutral foot-plate pose.

## Parameter file shape

Copy confirmed candidates into a file such as
`params/kinematic_params.yaml`:

```yaml
units: millimeter
source_step: assem_v3.STEP

ankle_center_base_mm: [0.0, 0.0, 0.0]

actuators:
  joint1:
    axis_point_base_mm: [0.0, 0.0, 0.0]
    axis_direction_base: [0.0, 0.0, 1.0]
    zero_angle_rad: 0.0
    dynamixel_id: 1
  joint4:
    axis_point_base_mm: [0.0, 0.0, 0.0]
    axis_direction_base: [0.0, 0.0, 1.0]
    zero_angle_rad: 0.0
    dynamixel_id: 2
  joint6:
    axis_point_base_mm: [0.0, 0.0, 0.0]
    axis_direction_base: [0.0, 0.0, 1.0]
    zero_angle_rad: 0.0
    dynamixel_id: 3

foot_plate:
  neutral_frame_base:
    origin_mm: [0.0, 0.0, 0.0]
    x_axis: [1.0, 0.0, 0.0]
    y_axis: [0.0, 1.0, 0.0]
    z_axis: [0.0, 0.0, 1.0]
  connection_points_foot_mm:
    p1: [0.0, 0.0, 0.0]
    p2: [0.0, 0.0, 0.0]
    p3: [0.0, 0.0, 0.0]
```

## Why this is still a candidate workflow

The current STEP export is AP203. It preserves solid geometry and part names,
but it does not reliably expose SolidWorks mate semantics. A dependency-free
parser can find cylinder axes, but it cannot always know which cylinder is a
motor output shaft versus a screw hole.

If possible, re-export as STEP AP242 with named reference geometry:

```text
motor_axis_1, motor_axis_2, motor_axis_3
p1, p2, p3
ankle_center
base_frame
foot_frame
```

That makes the final IK parameter extraction much less ambiguous.

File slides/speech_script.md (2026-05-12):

# Closing Presentation — 15-Minute Speech Script

Deck: `slides/closing_presentation.pptx` (19 slides, 16:9)
Target length: **~14 min 30 s** plus ~30 s for the closing.
Pace: ~140 words / minute. Total script: **≈ 2,000 words**.

Notation: each slide block lists the slide number, its title, the rough
time you should spend on it, and the script (English; matches the
colloquial style of `Roar.docx` so you can deliver it from memory).

---

## Slide 1 — Title  *(~20 s)*

> Good morning, everyone. Thank you for being here. My name is Yufei
> Zhang, and I am a graduate student in the Department of Mechanical
> Engineering, working with Professor Sunil K. Agrawal. Today I will
> walk you through my AMR research-course project: the **design and
> validation of a wearable ankle rehabilitation robot with an
> anatomically aligned 3-RRR spherical parallel mechanism**. The whole
> project — code, URDF, and this report — is open-source on GitHub at
> the link you see on the slide.

## Slide 2 — Outline  *(~25 s)*

> Here is what I will cover in the next fifteen minutes. I will start
> with the clinical motivation and the gap in the state of the art,
> then introduce the mechanism — including the shoe-tray foot plate,
> which is one of our two structural innovations. After that, the
> kinematics, the baseline control, the proposed Assist-As-Needed law,
> and the embedded hardware. Then I will spend a few minutes on the
> open-source ROS 2 / Gazebo simulation pipeline and the closed-loop
> tracking demo, before closing with the planned experiments, an
> honest project status, and an invitation for future students.

---

## Slide 3 — Motivation: Clinical Need  *(~45 s)*

> Let me start with the clinical picture. Ankle injuries — sprains,
> fractures, post-operative cases — and neurological deficits like
> stroke and foot-drop are extremely common. The standard of care today
> is therapist-driven manual mobilization of the talocrural, subtalar,
> and tibiofibular joints. You can see a representative example on the
> slide. The problem is that manual therapy is highly dependent on
> clinician experience, the dosing is qualitative, and the trajectory
> is not measurable. A robotic device can give you repeatability, dose
> control, and objective outcome metrics — and that is exactly what
> motivates this work.

## Slide 4 — State of the Art and the Gap  *(~60 s)*

> If we look at the existing literature, ankle rehab devices fall into
> two big families. On the top, you have **wearable exoskeletons** —
> powered, passive, or quasi-passive. They are portable and easy to
> deploy, but they typically constrain the joint to one or at most two
> degrees of freedom. They mostly cover dorsiflexion and
> plantarflexion, and they ignore inversion and yaw — which are
> exactly the motions you need for proprioceptive ankle rehab.
>
> On the bottom, you have **platform-style robots**. They give you the
> full three to six degrees of freedom, but they are stationary, and
> their geometric center of rotation does not coincide with the
> patient's talocrural joint. That mismatch produces parasitic shear
> across the ankle, which is a safety concern.
>
> Our target is the gap between these two families: **a wearable
> mechanism whose remote center of rotation is anatomically aligned
> with the human ankle**.

## Slide 5 — Biomechanical Motivation → 3-RRR SPM  *(~50 s)*

> The biomechanical reason this is even possible is shown on the left.
> The talocrural and subtalar complex has three rotation axes that
> converge near a single anatomical point. So if we use a mechanism
> whose joint axes also intersect at one common point — and place that
> point at the ankle — we get the same kinematic structure as the
> ankle itself. That is exactly what a **3-RRR spherical parallel
> mechanism** does. On the right, you can see the canonical 3-RRR
> diagram: nine revolute joints arranged so all axes converge at the
> spherical center O, producing exactly three rotational degrees of
> freedom — pitch, roll, and yaw.

---

## Slide 6 — Mechanism Design  *(~60 s)*

> Here is the wearable embodiment we have built. It is a strap-mounted
> device with a contoured shank cuff at the top, three identical RRR
> limbs spaced at 120 degrees, and a foot plate at the bottom. Two
> things are worth highlighting on this slide. First, the link lengths
> L₁ on the proximal side and L₂ on the distal side are deliberately
> annotated, because — as you will see in two slides — their ratio
> directly governs the singularity placement and the rotational
> isotropy of the device. Second, on the right you can see the
> assembled 3D-printed prototype, which is what we use today to verify
> fit, clearance, and bench-level integration.

## Slide 7 — Foot-Plate Innovation: Shoe-Tray Design  *(~75 s)*

> Now I want to spend a slide on what I think is the more clinically
> interesting innovation, which is the foot-plate design. The classic
> options in the literature are either a rigid foot plate, which only
> fits one foot size, or a soft sandal, which loses stiffness. Neither
> generalizes well across patients.
>
> Our choice — informed by a survey of comparable rehab devices — is
> a **shoe-tray foot plate**. The subject keeps their own shoes and
> just steps into the tray. Velcro and straps fix the foot in place
> across the dorsum and around the heel, and the wearable
> strap-mounted device drives the tray as a rigid body.
>
> This buys us three concrete things. First, **comfort**: there is no
> direct skin contact, and the patient walks on their own shoe sole,
> so longer training sessions become tolerable. Second,
> **generalization**: a single device fits a wide range of foot sizes,
> roughly EU 36 through 46, without re-manufacturing. Third,
> **clinical workflow**: don and doff is a one-step "step-in" motion,
> which matters in a real clinic.

## Slide 8 — CAD Multi-View  *(~35 s)*

> Three views of the same CAD: front, perspective, and top. The two
> things I want you to notice are the symmetric three-limb topology
> around the shank cuff and the open-back base ring, which is what
> makes the device tolerant to different calf circumferences.

## Slide 9 — Singularity-Aware Geometry  *(~60 s)*

> Now let me say a word about parallel singularities, because they
> are a real safety concern. At a parallel singularity the platform
> can pick up an extra, uncontrollable degree of freedom even when all
> the actuators are locked — meaning the device loses stiffness and
> can no longer resist external loads. In a rehab context that is
> dangerous.
>
> Following the analytical guidance of Saheb 2021 and Wu and Bai 2019
> for the 3-RRR architecture, we picked the link ratio ρ = L₂ / L₁
> approximately equal to 1.15. The plot on the left shows the per-leg
> reachable circles, and their intersection is the parallel-singularity
> -free common workspace. The result is a **roughly 20 % improvement
> in the global isotropy index** of the rotational Jacobian, with the
> singular curves pushed outward toward the workspace boundary.

## Slide 10 — Inverse Kinematics  *(~60 s)*

> The kinematics layer is what feeds the controller. We derived a
> closed-form inverse-kinematic expression per leg, which is great
> for offline workspace evaluation, and a numerical formulation for
> real-time control. The numerical version, summarized as Algorithm 1
> on the right, takes the desired roll, pitch, and yaw, computes each
> platform-side point, and then for each leg it scans a coarse motor-
> angle grid for a sign change in the leg residual, runs bisection
> inside the bracket, and picks the root closest to the previous
> control cycle to enforce branch continuity. The whole thing runs in
> the Python standard library, with no external dependencies, which is
> what allows the same code to run inside a ROS 2 node, inside a
> standalone CLI, and — eventually — inside the embedded loop on the
> Teensy.

## Slide 11 — Dynamics & Baseline PID  *(~40 s)*

> For the baseline controller we use three independent PID loops on
> the actuator angles. The two plots show the platform orientation
> response to a step reference under two tunings. On the left, an
> underdamped tuning gives oscillatory settling — basically a soft,
> compliant interaction. On the right, a critically damped tuning
> gives fast, monotonic convergence. The point is that even on a
> rigid SPM, the feedback gains alone modulate effective compliance,
> and these two regimes bracket the spectrum that the AAN controller
> we are about to introduce will interpolate online.

## Slide 12 — Assist-As-Needed Control  *(~60 s)*

> The AAN strategy comes from David Reinkensmeyer's group, and the
> idea is simple but powerful: the robot only assists when the patient
> actually needs help. If the patient can follow the trajectory on
> their own, the robot stays out of the way; if the patient starts
> drifting, the robot ramps up the assistance gradually. To estimate
> the patient torque without a distal force sensor, we subtract the
> model-predicted dynamic torque from the Dynamixel current
> measurement times the torque constant. The block on the right shows
> the architecture: a high-level supervisor computes gait phase and
> asymmetry, schedules the assistance torque, and a low-level loop
> tracks it on the actuator. To be transparent: AAN is **proposed and
> formulated**, not yet deployed on real hardware.

---

## Slide 13 — Embedded System & Hardware  *(~55 s)*

> Two photos on this slide. On the left, the prototype electronics
> stack: a Teensy 4.1 master in the center, an IMU breakout on the
> left for shank and foot orientation, and a TTL-to-RS-485
> transceiver at the bottom that bridges the master to the daisy-
> chained Dynamixel actuator bus. On the right, the actual servo-
> control wiring used on the bench: the XM430 motor at the top, the
> ROBOTIS U2D2 communication board in the middle, the dedicated power
> supply on the right, and the host laptop at the bottom. Closed-loop
> control runs at 1 kHz on the Teensy, with the encoder giving us
> roughly 0.088 degrees per tick — more than enough resolution for
> the angular precision required in ankle rehab.

## Slide 14 — Open-Source ROS 2 / Gazebo Pipeline  *(~60 s)*

> One of the deliverables I am most proud of is the open-source
> simulation pipeline. The whole thing is shipped as a single ROS 2
> ament-python package, MIT licensed, at the URL on the right. It
> bundles the URDF and Xacro, twenty-two STL meshes, four launch
> files for visualization and Gazebo, and the parallel-IK solver as a
> shared kinematic core. The screenshot on the left shows the
> workflow we use to gate URDF changes: we load the model into Gazebo,
> use the Apply Force and Torque dialog to inject a 100-newton-meter
> torque, and verify that the joint axes and inertials behave
> physically — no NaN inertias, no mesh interpenetration. This is
> what gives us confidence that any change to the robot description
> still simulates correctly before we touch hardware.

## Slide 15 — Closed-Loop Tracking Demo  *(~45 s)*

> Algorithm 2 shows the closed-loop tracking demo. It is dependency-
> free Python: it parses the URDF, treats joints 1, 4, and 6 as the
> three Dynamixel actuators, generates a slow sinusoidal reference at
> ±12 degrees of dorsi/plantarflexion and ±6 degrees of inversion, runs
> Algorithm 1 to get the motor angles, applies a 1.2 newton-meter
> torque cap and a 0.8 radian-per-second velocity cap from the safety
> supervisor, and logs everything to CSV. A screen capture of the demo
> running against the URDF model is shipped in the repository as
> `media/closed_loop_demo.mp4`, about 25 megabytes.

---

## Slide 16 — Planned Experiments  *(~75 s)*

> Now to the experimental design — which is **fully designed but not
> yet executed**.
>
> The metrics, on the left, are drawn from the rehab-robotics
> literature: the **Limb Symmetry Index** as the north-star clinical
> metric, **jerk** as a smoothness indicator, the **interaction torque**
> from our sensorless estimator, the gait-mat **center of pressure**,
> and the **human-contribution ratio** — what fraction of total
> joint torque comes from the patient under AAN.
>
> On the right, four sub-experiments. **E1**, simulated-impairment
> recovery, where we induce a controlled foot-drop with a small toe
> weight or a downward bias torque, and check whether AAN training
> brings the LSI from around 80 % back toward 95 %. **E2**, transparency
> — the device should not perturb natural gait under near-zero
> impedance, R squared above 0.95 between barefoot and device-on
> kinematics. **E3**, active participation, where the human-contribution
> ratio should rise across training sessions. And **E4**, the passive
> transfer effect of a CPM bout on overground gait. Statistics are
> within-subject paired tests with Bonferroni-Holm correction and
> bootstrap 95 % confidence intervals.

## Slide 17 — Implementation Status — Honest Snapshot  *(~75 s)*

> I want to be very transparent with this slide, because honest
> framing matters. Here is what is **done** today, in dark navy. The
> wearable 3-RRR mechanism, the shoe-tray foot plate, the closed-form
> and numerical IK, the open-source simulation controller, the
> closed-loop tracking demo against the URDF, the bench-tested
> embedded electronics, and the full ablation-experiment design with
> quantitative metrics — these are all delivered, all in the repo,
> and all reproducible.
>
> Here is what is **proposed but not yet hardware-deployed**, in
> grey: the AAN control law itself. It is fully formulated, but it
> needs to ride on top of a real Dynamixel current loop before we
> can claim it works.
>
> And here is what is **not yet done**, in orange: first, standalone
> untethered operation — by which I mean battery-driven, free
> wearable walking on the gait mat. Second, the human-subject
> experiments themselves. The platform is built and runnable; the
> subject trials are simply the next milestone.

## Slide 18 — Conclusion & Open Invitation  *(~60 s)*

> So to summarize. The three concrete deliverables are: a wearable,
> anatomically aligned 3-RRR mechanism with a shoe-tray foot plate
> that fits a wide range of foot sizes; a closed-form plus numerical
> inverse-kinematic stack that runs in real time; and an MIT-licensed
> ROS 2 / Gazebo simulation controller that has been verified end-to-
> end against the URDF.
>
> Two open items remain: standalone untethered operation, and the
> subject experiments E1 through E4.
>
> And here is the honest invitation. The simulation codebase, the
> wearable hardware design, and the experimental protocol together
> form a turn-key starting point. If a future student in our group is
> interested in this direction, they can pull the repository, plug in
> their own subject trials, and the project picks up exactly where
> this report leaves off. I would be very happy to support that.

## Slide 19 — Thank You  *(~15 s)*

> Thank you for your attention. I am happy to take questions.

---

## Time budget

| Block | Slides | Target |
|---|---|---|
| Opening | 1 – 2 | 0:45 |
| Motivation & gap | 3 – 4 | 1:45 |
| Mechanism + shoe-tray | 5 – 8 | 3:40 |
| Kinematics + control | 9 – 12 | 3:20 |
| Hardware + open-source | 13 – 15 | 2:40 |
| Experiments + status | 16 – 17 | 2:30 |
| Closing | 18 – 19 | 1:15 |
| **Total** | **19 slides** | **~15:55** |

If you find yourself running long on the day, the easiest cuts are:
slide 8 (CAD multi-view, optional), slide 11 (PID tunings, can be one
sentence), slide 15 (closed-loop demo, can be skipped if you screen
the video instead). Cutting all three saves ~2 minutes and brings the
talk to ~13:30.

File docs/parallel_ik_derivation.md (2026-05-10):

# RH1 Parallel Ankle IK Derivation

This is the IK model used by `rh1/parallel_ik.py`. It is written for the
current project stage: three XM430-W350-R motors drive a 3-DOF spherical
parallel ankle mechanism, and the foot plate command is an orientation.

## Frames and Pose Command

Use a fixed base frame `{B}` and a neutral foot-plate frame `{F}`. The ankle
center is `C_B` in the base frame.

The desired foot plate orientation is:

```text
R_BF = Rz(yaw) * Ry(pitch) * Rx(roll)
```

where:

```text
pitch = dorsiflexion / plantarflexion
roll  = inversion / eversion
yaw   = internal / external rotation
```

For each leg `i`, define the foot-plate connection point in the neutral foot
frame:

```text
p_i^F
```

When the plate rotates, that point becomes:

```text
P_i^B = C_B + R_BF * p_i^F
```

## Actuator-Side Point

For each active motor axis:

```text
B_i^B = one point on the motor axis
u_i^B = unit direction of the motor axis
```

Define one actuator-side horn/rocker point at motor zero:

```text
A_i0^B
```

When the motor angle is `q_i`, that point rotates around the motor axis:

```text
A_i^B(q_i) = B_i^B + Rot(u_i^B, q_i - q_i0) * (A_i0^B - B_i^B)
```

`Rot(u, q)` is Rodrigues rotation around axis `u`.

## Constraint Equation

Each leg is modeled as an effective rigid link of length `L_i` between the
actuator-side point and the foot-plate point:

```text
|| P_i^B - A_i^B(q_i) || = L_i
```

So the scalar IK equation for each motor is:

```text
f_i(q_i) = || P_i^B - A_i^B(q_i) || - L_i = 0
```

The solver samples the allowed motor range, finds sign-change brackets, and
then uses bisection. If more than one root exists, it chooses the one closest to
the previous motor angle.

## What Parameters Are Still Needed

The STEP extraction already gives strong candidates for the three motor axes,
but a complete IK model still needs:

```text
A_i0^B: actuator-side horn/rocker point at zero angle
p_i^F: foot-plate connection point in foot frame
L_i: effective rigid link length
q_i0: motor zero offset relative to the CAD neutral pose
```

These can be confirmed from SolidWorks, or fitted from calibration data using
motor encoders plus Vive tracker foot-plate orientation.

## Control Pipeline

Once parameters are confirmed:

```text
desired roll/pitch/yaw
  -> ParallelAnkleIK.solve_orientation()
  -> q1/q4/q6 in radians
  -> Dynamixel goal ticks
  -> sync write to XM430-W350-R
  -> read back position/current/error
  -> Vive tracker and gait mat metrics
```

## Run the Solver

Use the synthetic smoke-test parameters to verify the command line:

```bash
python3 scripts/parallel_ik_demo.py params/parallel_ik_params.example.json
```

Use real RH1 geometry only after filling a confirmed parameter file:

```bash
python3 scripts/parallel_ik_demo.py params/parallel_ik_params.confirmed.json \
  --pitch-deg 8 \
  --roll-deg 4 \
  --yaw-deg 0
```

The fully automatic STEP bootstrap file is intentionally approximate. Use a
looser residual tolerance only for software bring-up:

```bash
python3 scripts/auto_generate_parallel_ik_params.py
python3 scripts/parallel_ik_demo.py params/parallel_ik_params.autogenerated.json \
  --pitch-deg 2 \
  --roll-deg 1 \
  --tolerance-mm 1.0
```

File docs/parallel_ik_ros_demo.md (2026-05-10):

# RH1 Parallel IK ROS Demo

This demo lets you command foot-plate `pitch/roll/yaw` values and see the
corresponding `joint1/joint4/joint6` angles in ROS 2/RViz.

## Build

```bash
cd ~/rh1_ws
colcon build --packages-select rh1
source install/setup.bash
```

## Launch RViz demo

```bash
ros2 launch rh1 parallel_ik_pose_demo.launch.py
```

Start with a nonzero pose:

```bash
ros2 launch rh1 parallel_ik_pose_demo.launch.py pitch_deg:=2 roll_deg:=1 yaw_deg:=0
```

## Change pose live

In another terminal:

```bash
source ~/rh1_ws/install/setup.bash
ros2 param set /parallel_ik_pose_demo pitch_deg 5.0
ros2 param set /parallel_ik_pose_demo roll_deg 2.0
ros2 param set /parallel_ik_pose_demo yaw_deg 0.0
```

The node logs the solved motor angles and XM430 position ticks:

```text
foot pitch=2.00 roll=1.00 yaw=0.00 deg ->
joint1=14.00 deg tick=2207; joint4=20.50 deg tick=2281; joint6=10.50 deg tick=2167
```

## Important safety note

The default file `config/parallel_ik_autogenerated.json` is fully automatic and
unverified. It is intended for visualization and software bring-up. Use low
angles, low speed, and current limits before using any generated IK output on
real XM430-W350-R motors.

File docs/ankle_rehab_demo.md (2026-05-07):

# RH1 Ankle Rehab Closed-Loop Demo

This repository currently contains a ROS 2 robot description package exported
from SolidWorks. The runnable demo is:

```powershell
python scripts\ankle_rehab_closed_loop_demo.py
```

The script parses `urdf/rh1.urdf`, uses `joint1`, `joint4`, and `joint6` as the
three virtual XM430-W350-R actuators, tracks a slow ankle rehabilitation
trajectory, and writes feedback data to:

```text
demo_output/ankle_rehab_closed_loop.csv
```

## Control Demo

The default motion is intentionally conservative for early ankle rehab testing:

- dorsiflexion/plantarflexion amplitude: `12 deg`
- inversion/eversion amplitude: `6 deg`
- cycle frequency: `0.05 Hz`
- smooth startup ramp: `3 s`
- torque limit used in simulation: `1.2 Nm`
- velocity limit used in simulation: `0.8 rad/s`

The XM430-W350-R stall torque is treated as an upper hard cap, but this demo
uses a lower patient-side torque limit by default. Tune this only after the
mechanism is unloaded, then tested with a fixture, and only then with a human
subject under lab safety procedures.

Useful command examples:

```powershell
python scripts\ankle_rehab_closed_loop_demo.py --duration 60
python scripts\ankle_rehab_closed_loop_demo.py --dorsi-amp-deg 8 --invert-amp-deg 4
python scripts\ankle_rehab_closed_loop_demo.py --torque-limit-nm 0.8 --velocity-limit-rad-s 0.5
```
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

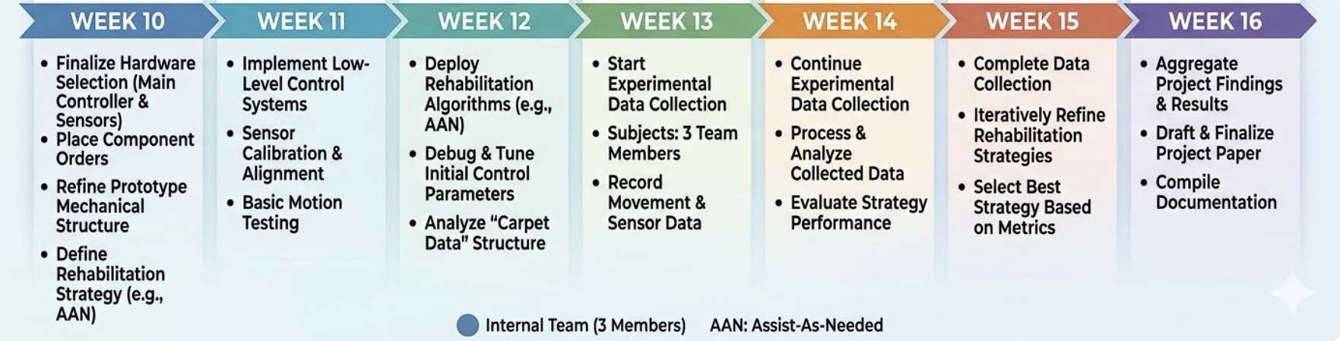
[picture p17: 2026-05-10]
report/figures/timeline.png

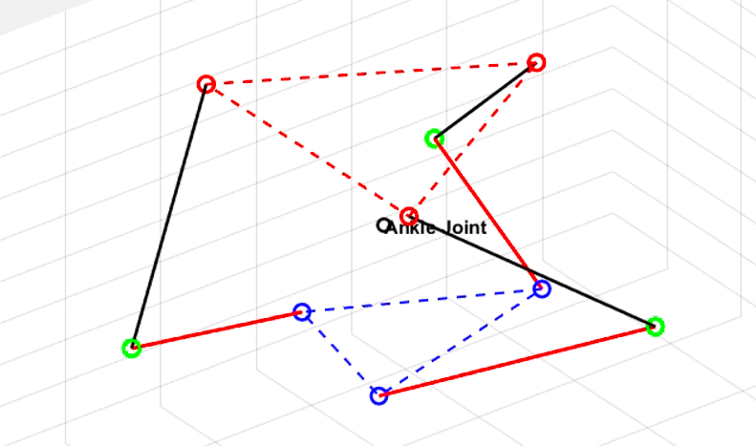
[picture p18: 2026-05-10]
report/figures/matlab_simulation.png

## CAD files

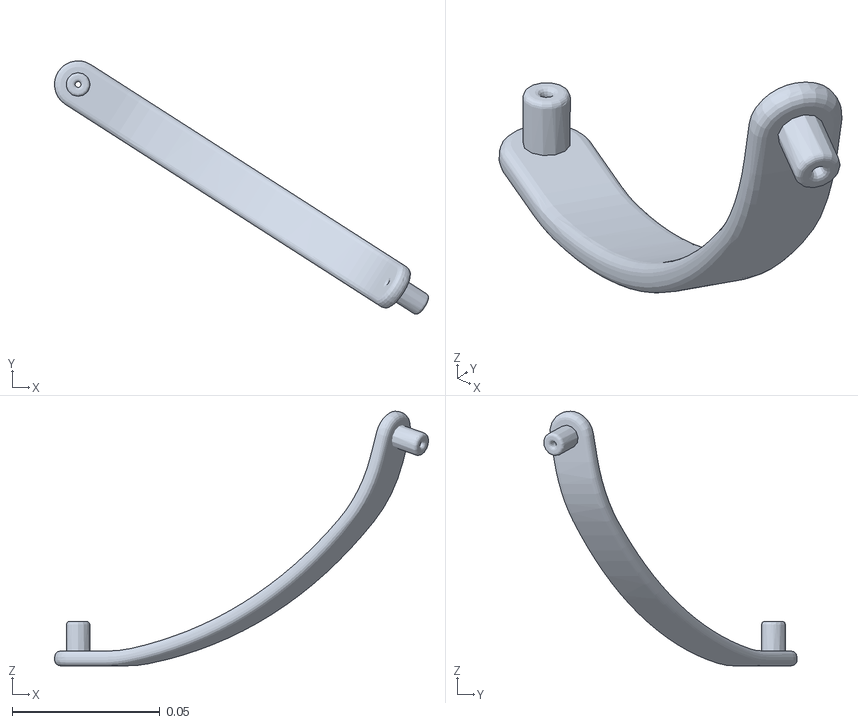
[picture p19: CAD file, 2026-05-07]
meshes/collision/Link1.STL
0.126 x 0.0856 x 0.0861

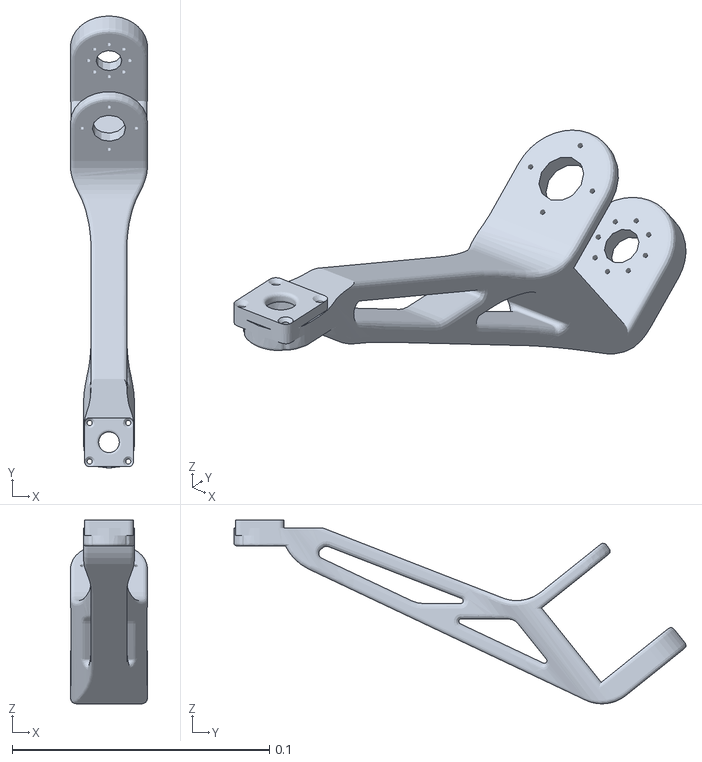
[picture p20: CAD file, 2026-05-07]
meshes/visual/Link5.STL
0.03 x 0.176 x 0.0713

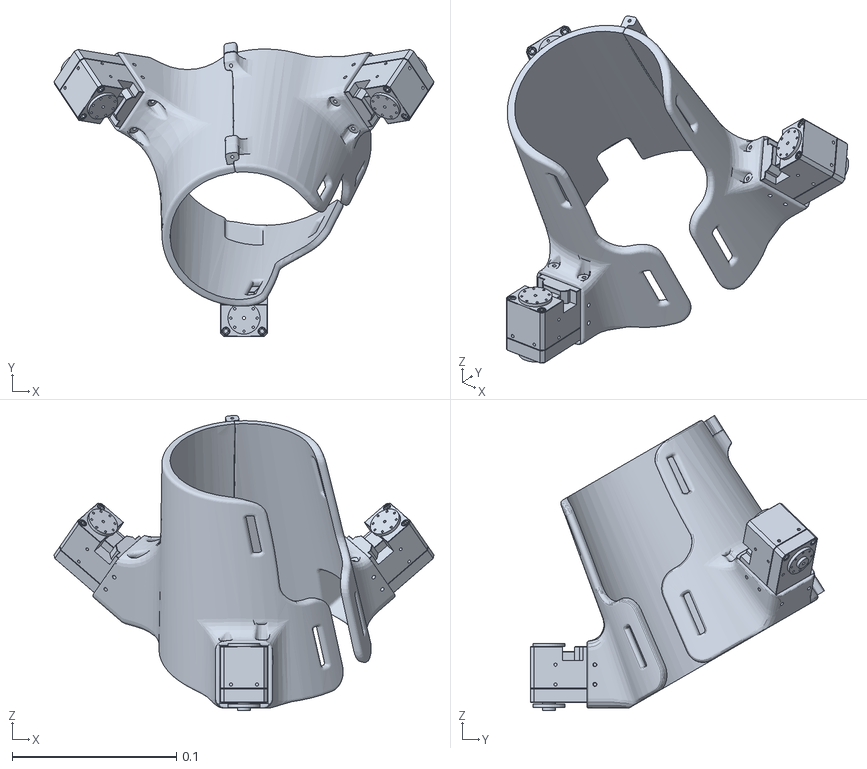
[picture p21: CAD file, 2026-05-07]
meshes/collision/Link3.STL
0.232 x 0.179 x 0.18

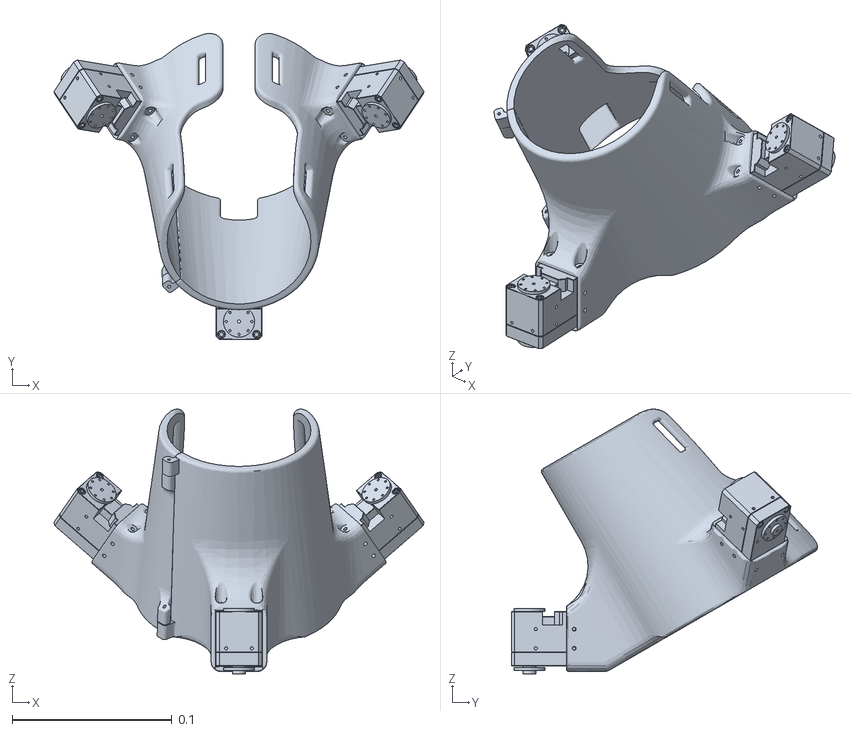
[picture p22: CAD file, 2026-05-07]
meshes/visual/Link7_3.STL
0.232 x 0.192 x 0.166

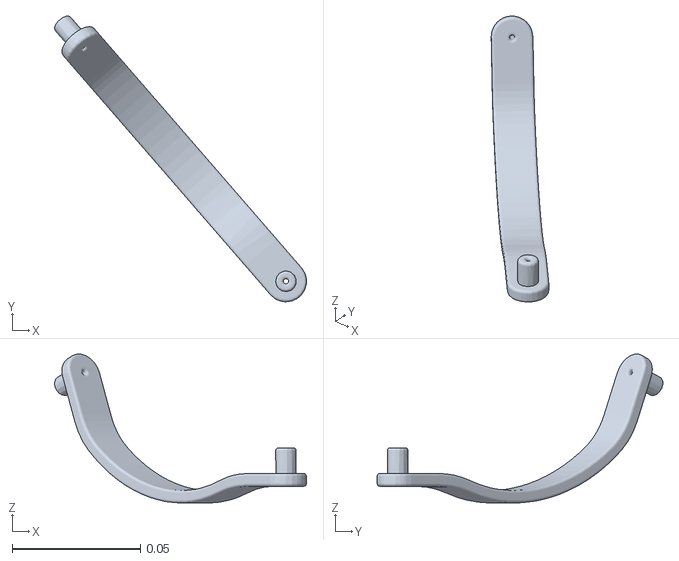
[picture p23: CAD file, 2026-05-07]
meshes/visual/Link4.STL
0.0981 x 0.111 x 0.0579

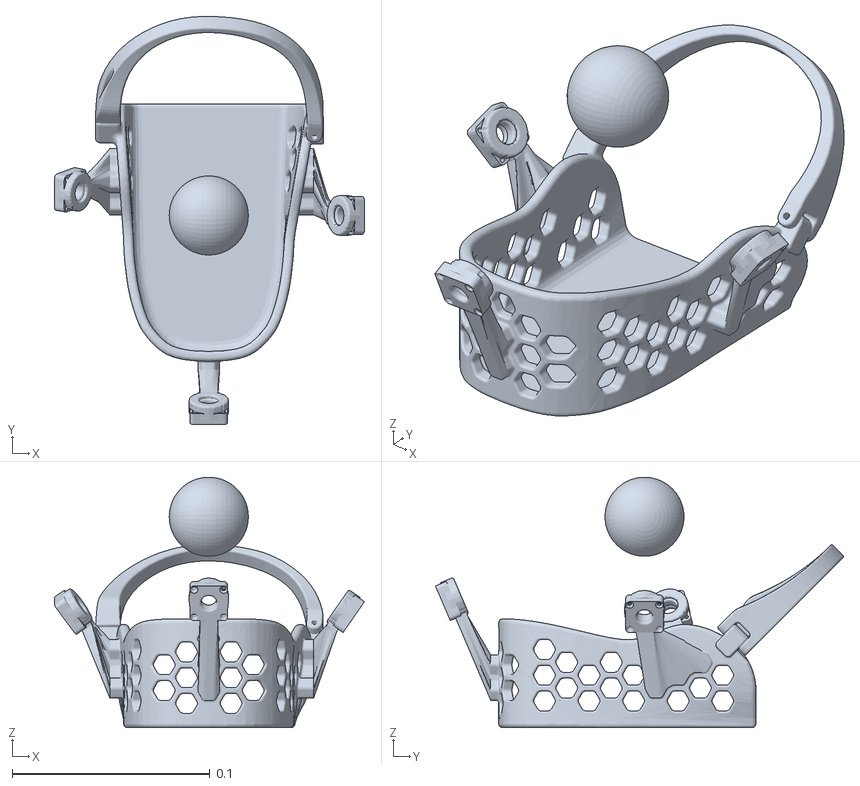
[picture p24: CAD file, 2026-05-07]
meshes/visual/base_link.STL
0.157 x 0.206 x 0.127

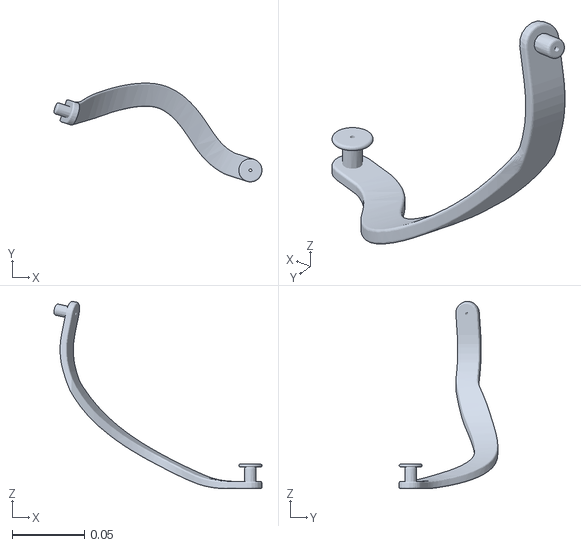
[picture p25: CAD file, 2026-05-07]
meshes/visual/Link6.STL
0.144 x 0.0683 x 0.129

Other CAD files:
meshes/visual/Link2.STL
meshes/collision/Link2.STL
meshes/collision/Link7.STL
meshes/collision/Link5_3.STL
meshes/visual/Link7.STL
meshes/visual/Link5_3.STL

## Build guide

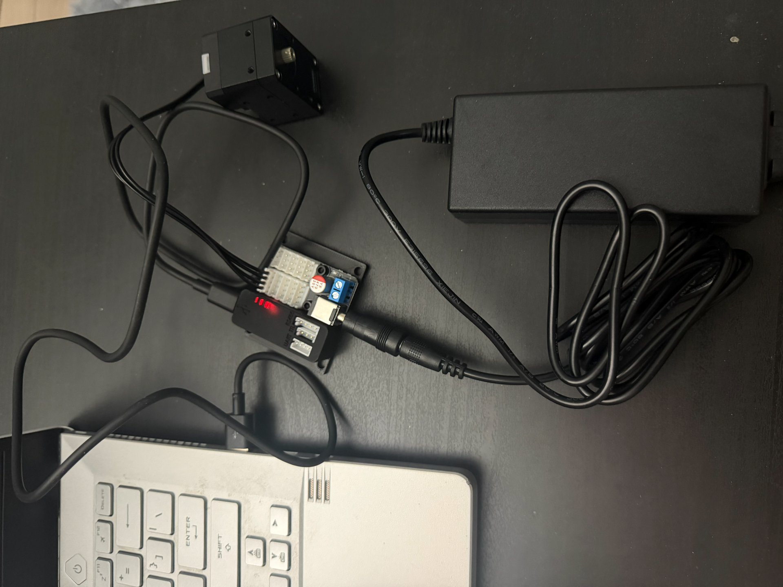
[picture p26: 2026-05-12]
report/figures/hardware_wiring_diagram.jpg

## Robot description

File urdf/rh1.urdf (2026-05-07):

<?xml version="1.0"?>
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
<robot name="rh1">
    <link name="world">
  </link>
  <joint name="base_to_wrold" type="fixed">
    <parent link="world"/> 
    <child link="base_link"/>
  </joint> 



  <link name="base_link">
    <inertial>
      <origin xyz="-9.89578390172552E-05 0.00396138423389414 0.0411335608160095" rpy="0 0 0" />
      <mass value="0.170511519490799" />
      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
    </inertial>
    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
  </link>
  <link name="Link1">
    <inertial>
      <origin xyz="0.0595761636128956 -0.0381714139611611 0.0213524140159522" rpy="0 0 0" />
      <mass value="0.0139403061893374" />
      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
    </inertial>
    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
  </link>
  <joint name="joint1" type="revolute">
    <origin xyz="-0.00024316 -0.093653 0.063941" rpy="-1.1653 0 0" />
    <parent link="base_link" />
    <child link="Link1" />
    <axis xyz="0 0 1" />
    <limit lower="-3.14" upper="3.14" effort="0" velocity="0" />
  </joint>
  <link name="Link2">
    <inertial>
      <origin xyz="7.33342596648257E-08 0.0919365461921934 -0.0349000401041466" rpy="0 0 0" />
      <mass value="0.0488710971031766" />
      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
    </inertial>
    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
  </link>
  <joint name="joint2" type="revolute">
    <origin xyz="0.11105 -0.071151 0.068863" rpy="1.0806 0.92034 -2.5422" />
    <parent link="Link1" />
    <child link="Link2" />
    <axis xyz="0 0 -1" />
    <limit lower="-3.14" upper="3.14" effort="0" velocity="0" />
  </joint>
  <link name="Link3">
    <inertial>
      <origin xyz="-0.0040437 0.094764 0.057759" rpy="0 0 0" />
      <mass value="0.39517" />
      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
    </inertial>
    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
  </link>
  <joint name="joint3" type="revolute">
    <origin xyz="0 0.1355 -0.031331" rpy="0.67602 0 0" />
    <parent link="Link2" />
    <child link="Link3" />
    <axis xyz="0 0 1" />
    <limit lower="-3.14" upper="3.14" effort="0" velocity="0" />
  </joint>
  <link name="Link4">
    <inertial>
      <origin xyz="-0.0444266184876221 0.0512750104381572 0.00184714563025645" rpy="0 0 0" />
      <mass value="0.0131177442111698" />
      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
    </inertial>
    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
  </link>
  <joint name="joint4" type="revolute">
    <origin xyz="-0.070045 0.01858 0.058418" rpy="0.97468 0 1.388" />
    <parent link="base_link" />
    <child link="Link4" />
    <axis xyz="0 0 1" />
    <limit lower="-3.14" upper="3.14" effort="0" velocity="0" />
  </joint>
  <link name="Link5">
    <inertial>
      <origin xyz="1.19788753145667E-05 0.0919350834021235 -0.0353942215193617" rpy="0 0 0" />
      <mass value="0.0488711044215503" />
      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
    </inertial>
    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
  </link>
  <joint name="joint5" type="revolute">
    <origin xyz="-0.082937 0.095722 0.033269" rpy="1.0995 0.56705 0.44676" />
    <parent link="Link4" />
    <child link="Link5" />
    <axis xyz="0 0 -1" />
    <limit lower="-3.14" upper="3.14" effort="0" velocity="0" />
  </joint>
  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
  <link name="Link6">
    <inertial>
      <origin xyz="-0.0739475687831217 0.0349537427983839 0.034940331960659" rpy="0 0 0" />
      <mass value="0.0212392066716247" />
      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
    </inertial>
    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
  </link>
  <joint name="joint6" type="revolute">
    <origin xyz="0.071451 0.0056756 0.056943" rpy="0.96525 0 -1.5708" />
    <parent link="base_link" />
    <child link="Link6" />
    <axis xyz="0 0 1" />
    <limit lower="-3.14" upper="3.14" effort="0" velocity="0" />
  </joint>
  <link name="Link7">
    <inertial>
      <origin xyz="5.98254873418469E-08 0.0919365571507467 -0.0350319483412185" rpy="0 0 0" />
      <mass value="0.0488710825057113" />
      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
    </inertial>
    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
  </link>
  <joint name="joint7" type="revolute">
    <origin xyz="-0.12811 0.040995 0.11558" rpy="1.942 0.96525 1.5708" />
    <parent link="Link6" />
    <child link="Link7" />
    <axis xyz="0 0 -1" />
    <limit lower="-3.14" upper="3.14" effort="0" velocity="0" />
  </joint>
  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

</robot>

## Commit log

2026-05-07 Add RH1 ankle rehab simulation demo
    [Link1.STL, Link2.STL, Link3.STL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]
2026-05-10 Reorganize repo: parallel-IK control code, params, docs, and report
    Promotes the project from a SolidWorks-exported snapshot into a
    publication-ready research codebase for the wearable 3-RRR spherical
    parallel ankle rehabilitation robot.
    Code and assets
    - Add the parallel inverse-kinematic solver (rh1/parallel_ik.py),
    ROS 2 interactive pose demo (rh1/parallel_ik_pose_demo.py), and
    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
    [ankle_rehab_closed_loop.csv]
2026-05-10 Add closed-loop demo recording
    A ~25 MB MP4 capture of the closed-loop ankle-rehab tracking demo
    (scripts/ankle_rehab_closed_loop_demo.py running against urdf/rh1.urdf).
    - Add media/closed_loop_demo.mp4
    - Reference the clip from README.md (intro paragraph + repo layout)
2026-05-10 report: retitle, add open-source/Gazebo section, drop stale milestone
    Re-scopes the paper around what is actually delivered (mechanism + IK +
    open-source ROS 2 / Gazebo pipeline) and de-emphasises the AAN control
    work that is still proposed.
    Title and abstract
    - Retitle to "A Wearable 3-RRR Spherical Parallel Ankle Rehabilitation
    Robot: Mechanism, Inverse Kinematics, and an Open-Source ROS 2 /
    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
2026-05-10 report: retitle, code link in author block, pseudocode, smaller Fig.9
    Title and author block
    - Retitle to "Design, Inverse Kinematics, and Validation of a Wearable
    3-RRR Spherical Parallel Ankle Rehabilitation Robot" - drops the
    "ROS 2 / Gazebo Simulation Pipeline" framing because the project is
    a physical device, not a simulation-only effort
    - Surface the GitHub repo URL right under the author email line
    (matches the convention used by recent IEEE / RA-L rehab robotics
    papers); shorten the \thanks footnote to defer to that URL
    Section VIII rewrite (Open-Source Design and Validation Pipeline)
    - Drop the path-heavy repository table and the verbatim CLI block that
    were overflowing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
2026-05-12 Add closing-presentation PPT generator and 18-slide deck
    Adds an end-of-project closing presentation that mirrors the report's
    section ordering and is ready for a 15-20 minute defense.
    Build script
    - scripts/build_pptx.py: programmatic PPTX builder using python-pptx
    (no Office/Keynote dependency); 16:9 layout, navy + accent palette,
    consistent header/footer, page numbers
    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
2026-05-12 Track roar_speech_draft.docx; tighten gitignore (root-only docx/pdf, ~$ lock files)
